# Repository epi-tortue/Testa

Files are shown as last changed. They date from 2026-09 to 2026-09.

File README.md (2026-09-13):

# Testa - conception de coque

Outil de conception et d'optimisation de la coque d'un bateau autonome électrique pour le
[Microtransat](https://www.microtransat.org/) (LOA < 2,4 m), selon la solution
[S1 - coque à ailes inondables](https://epi-tortue.github.io/docs/solutions/s1-coque/) :
coque à déplacement **auto-redressante par la forme**, sans quille lestée, avec deux
**ailes latérales creuses** percées de trous qui portent les panneaux solaires, un
**pont bombé étanche** qui joue le rôle du pont intérieur, et un **lest interne**.

L'objectif est de trouver la géométrie (coque + ailes + lest) qui **maximise l'énergie
solaire produite par rapport à l'énergie de propulsion**, sous contrainte
d'auto-redressement depuis 180° ailes noyées, de franc-bord et de largeur hors-tout.

## Installation

```bash
python3 -m venv .venv && source .venv/bin/activate
pip install -r requirements.txt
```

## Utilisation

```bash
python3 -m coque.params                 # bornes et défauts des 19 variables
python3 -m coque.mesh                   # maillage de la coque de référence + contrôle d'étanchéité
python3 resolve.py --test               # rapport complet de la coque de référence -> outputs/test_*
python3 resolve.py --test --valeurs x.json
python3 resolve.py                      # optimisation CMA-ES multi-départs (reprise automatique)
python3 chercher_coques_redressantes.py --n 256   # balayage Sobol -> CSV + top coques GO
python3 trace_top_go.py                 # courbes GZ réel / A / B des meilleures coques
pytest                                  # validation (formes analytiques, étanchéité, non-régression)
```

## Ce que calcule le score

```
score = production solaire [Wh/j] × cos(gîte moyenne sous 7 m/s)
        / énergie pour 1 km à 1 m/s [Wh/km]  -  pénalités
```

- **Production** : aire projetée du pont de coque + dessus des ailes, × taux de couverture,
  × 615 Wh/m²/j (moyenne route Atlantique N., voir `plt/pont/pont_solaire.py`), × cos de
  la gîte statique sous le vent moyen `VENT_MOYEN` : une coque molle navigue couchée et
  ses panneaux ne voient plus le ciel.
- **Énergie** : frottement ITTC-57 + facteur de forme + vague forfaitaire + fardage
  (vent apparent moyen `VENT_APPARENT`), rendements hélice et chaîne électrique.
- **Tenue au vent** (`vent.py`) : couple de gîte = pression dynamique × Cd × (œuvres
  mortes × cos φ + plateau solaire × sin φ) × bras, comparé à M·g·GZ(φ). La gîte
  d'équilibre sous `VENT_GITE` (10 m/s, ~20 nds) doit rester sous `GITE_VENT_MAX` (12°)
  et sous l'angle d'inondation moins `MARGE_INOND_VENT` (5°). C'est ce critère qui
  dimensionne la raideur initiale, plus que le plancher GM0.
- **Rendement des panneaux** : sous le vent moyen (7 m/s) la gîte doit rester sous
  `GITE_MOYENNE_MAX` (5°) et l'aile sous le vent hors de l'eau avec `MARGE_CONTACT_AILE`
  (2°) : une aile qui traîne n'est pas dans le modèle de traînée, et c'est la coque nue
  qui doit tenir le vent moyen, pas l'appui sur une aile. En dessous de l'angle de
  contact de l'aile, la courbe GZ utilisée pour la gîte sous le vent est GM0·sin φ (coque
  seule) : interpoler le segment 2°–10° de la grille vers un GZ(10°) déjà porté par l'aile
  surestimait la raideur à 4–6° et l'optimiseur s'y était engouffré (écart grille/rapport
  de 49 points sur un run).
- **Robustesse** : tous les critères GZ sont évalués avec KG relevé de `MARGE_KG` (1 cm,
  soit ~300 g oubliés sur le pont) : GZ_rob(φ) = GZ(φ) − 1 cm × sin φ.
- **Pénalités** (continues, 200 points par cm de déficit, 20 points par degré ou par
  mm·rad) : GZ_rob < 3 cm sur [90°, 170°], GZ_rob < 0 quelque part (grille + point juste
  après l'inondation de chaque aile), GM0 < 3 cm (équilibre dédié à 2°, indépendant du pas
  de la grille), aire sous GZ_rob de 0 à 60° < 15 mm·rad (réserve dynamique en vagues),
  gîte sous 10 m/s > 12°, aile basse noyée sous 10 m/s, aile basse inondée avant 25° de
  gîte (angle encadré par bissection, la contrainte porte sur la borne basse de
  l'intervalle), franc-bord < 8 cm, ailes dans l'eau au repos, largeur hors-tout > 0,80 m.
  Géométrie impossible / maillage non étanche / coque qui coule : score −10 000 (toujours
  pire qu'une coque valide).
- **Bornes constructibles** : ailes ≥ 4 cm d'épaisseur, nervure de rive ≥ 1 cm, pont
  bombé ≥ 3 cm. Un optimiseur qui ne paie pas la structure met tout à zéro.
- **Piège ailes sèches** : après un chavirage, les ailes mettent des minutes à se remplir
  (vidange calculée ≈ 150 s pour 12 trous de 8 mm). Tant qu'elles portent, la courbe
  « état A » a en général un équilibre stable vers 150–160° (bateau couché sur une aile).
  À chaque équilibre stable de l'état A sur [90°,180°], les trous d'une aile doivent être
  à ≥ `PROFONDEUR_TROU_MIN` (2 cm) sous l'eau, sinon rien ne remplit l'aile et le bateau
  y reste : 200 points par cm manquant. Le rapport liste ces positions. Corollaire de
  construction : des **évents** sur la face intérieure des ailes, sinon l'air ne sort pas.
- **Assiette** : l'équilibre au repos est toujours à assiette libre ; en « assiette
  bloquée » (grille de l'optimiseur) les autres gîtes sont calculées à l'assiette du
  repos, pas à 0. Tirant d'eau, franc-bord (au livet du maître-bau) et garde des ailes
  (point le plus bas des caissons) sont mesurés sur ce plan de flottaison réel.
- **Coque GO de référence** : `references/go_reference.json` est GO sous tous ces
  critères (GM0 13 cm, gîte 4° sous 7 m/s et 12° sous 10 m/s, inondation à 30°,
  GZ_min[90°,170°] 3,1 cm, score ≈ 305). Point de départ conseillé : `python3 resolve.py --valeurs
  references/go_reference.json`. Sur 192 tirages Sobol aléatoires, aucun n'est GO : la
  région faisable est étroite, partir d'une coque GO économise beaucoup de budget.
- **Anti-artefact de grille** : pendant l'optimisation (pas 10°) les seuils GZ/GM0 sont
  surcotés de `MARGE_GRILLE` (2 mm) et le seuil d'inondation de `MARGE_GRILLE_DEG`
  (0,625°, la résolution de la bissection au pas fin) ; l'optimum de chaque run CMA-ES est ensuite revalidé
  au pas fin (5°, assiette libre) et c'est ce score-là qui classe les runs et qui est
  affiché. Un candidat qui n'est « GO » que sur la grille grossière ne peut plus gagner.
  GZ est aussi évalué juste après l'inondation de chaque aile (là où la courbe chute entre
  deux points de grille) et entre dans le contrôle GZ ≥ 0.
- **Rapport** : chaque rapport (et la fin de chaque run CMA-ES) affiche le bilan des
  marges de toutes les contraintes (valeur, seuil, marge, « au seuil » / « VIOLÉE ») et le
  tableau des 19 variables avec leurs bornes et les butées. Une variable en butée est
  dessinée par la borne, pas par la physique : c'est là qu'il faut regarder en premier.
- **Deux classements** : la pénalité étant continue, un quasi-GO peut avoir un meilleur
  score qu'un vrai GO. `resolve.py` exporte donc en priorité la meilleure coque GO au pas
  fin (préfixe `optim`) et, si le meilleur score fin est une autre coque NO-GO, l'exporte
  aussi (préfixe `optim_nogo`).

## Modèle de stabilité

La courbe GZ 0–180° est calculée par carènes inclinées sur les maillages (coque + deux
ailes). Les ailes portent tant que leurs **trous** (bord supérieur extérieur) sont hors
d'eau ; dès qu'un trou passe sous la flottaison à l'équilibre, l'aile est **noyée
définitivement** et ne porte plus (courbe "réelle", CDC §6). Les courbes pures A (ailes
sèches) et B (ailes noyées) sont disponibles pour les rapports. Un filtre rapide (GZ à
172° coque seule) élimine en 0,4 s les coques stables à l'envers.

## Organisation

```
coque/            package
  params.py       constantes, 19 variables libres (bornes + défauts), validité
  geometrie.py    Bézier rationnelle, loft d'anneaux -> maillage étanche orienté
  mesh.py         CoqueMesh : coque paramétrique
  ailes.py        Ailes : caissons (largeur, épaisseur, bord épaissi, trous)
  masses.py       modèle de masses (structure calculée, charge, lest, panneaux)
  hydro.py        Carene : tirant d'eau, surface mouillée, Cb, Cp
  gz.py           Vessel : équilibre incliné, courbe GZ, métriques
  stabilite.py    verdict d'auto-redressement (inondation séquentielle des ailes)
  propulsion.py   résistance, puissance, énergie
  energie.py      production solaire
  objectif.py     evaluer(valeurs) -> dict complet ; score(curseur) -> float
  optim.py        CMA-ES multi-départs + checkpoints
  export.py       STL, JSON, tracé GZ
resolve.py, chercher_coques_redressantes.py, trace_top_go.py   scripts
tests/            pytest
checkpoints/      état de l'optimisation en cours (reprise automatique)
```

## Variables libres (19)

| Groupe | Variables |
|---|---|
| Coque (15) | `L_COQUE`, `B_MAX`, `CREUX`, `DEADRISE`, `FLARE`, `F_BOUCHAIN`, `W_BOUCHAIN`, `X_MAITRE`, `REMPL_AV`, `REMPL_AR`, `B_ETRAVE`, `B_TABLEAU`, `ROCKER_AV`, `ROCKER_AR`, `HAUTEUR_BOMBE` |
| Ailes (3) | `AILE_LARGEUR`, `AILE_EPAISSEUR`, `AILE_BORD` (épaississement du bord extérieur) |
| Masses (1) | `LEST` (kg, au fond) |

Correspondance avec les 5 paramètres d'optimisation du CDC §7 : volume des ailes
(`AILE_LARGEUR`, `AILE_EPAISSEUR`), forme de section (`DEADRISE`, `FLARE`, bouchain),
pont intérieur (`HAUTEUR_BOMBE`), hauteur de G (`LEST`), bord des ailes (`AILE_BORD`).

## Hypothèses à caler

`M_SURF_AILE`, `M_SURF_SOLAIRE`, `VENT_APPARENT`, `SOLAIRE_WH_M2_JOUR`, le terme de vague
(`c_vague`, `r_hump_max`) et les positions des masses (`masses.py`) sont des estimations :
voir les commentaires de `coque/params.py`.

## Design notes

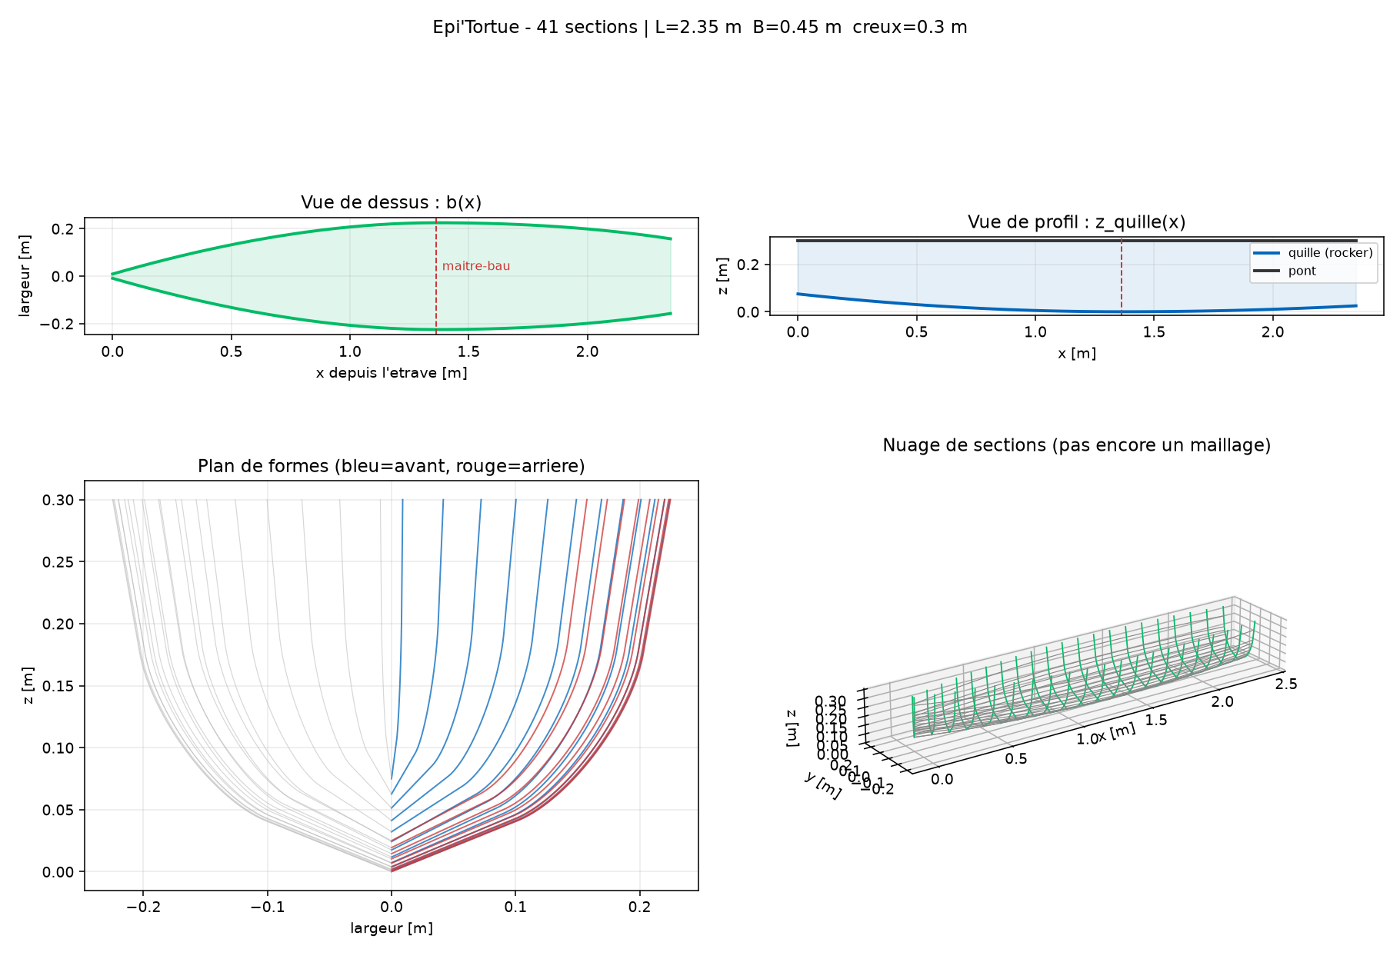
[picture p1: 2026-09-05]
plt/sections_etape2.png

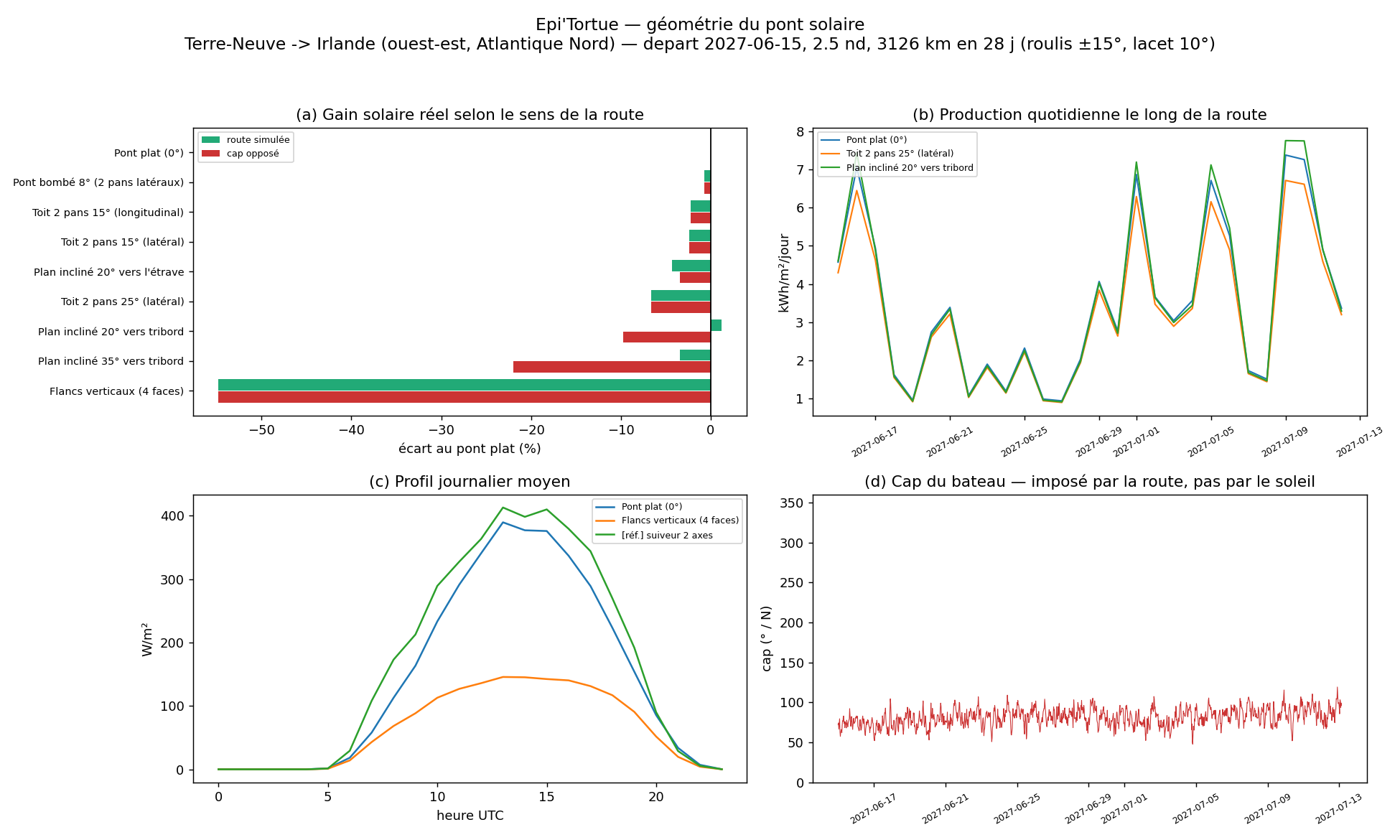
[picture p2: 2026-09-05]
plt/pont/exemple_route_nord.png

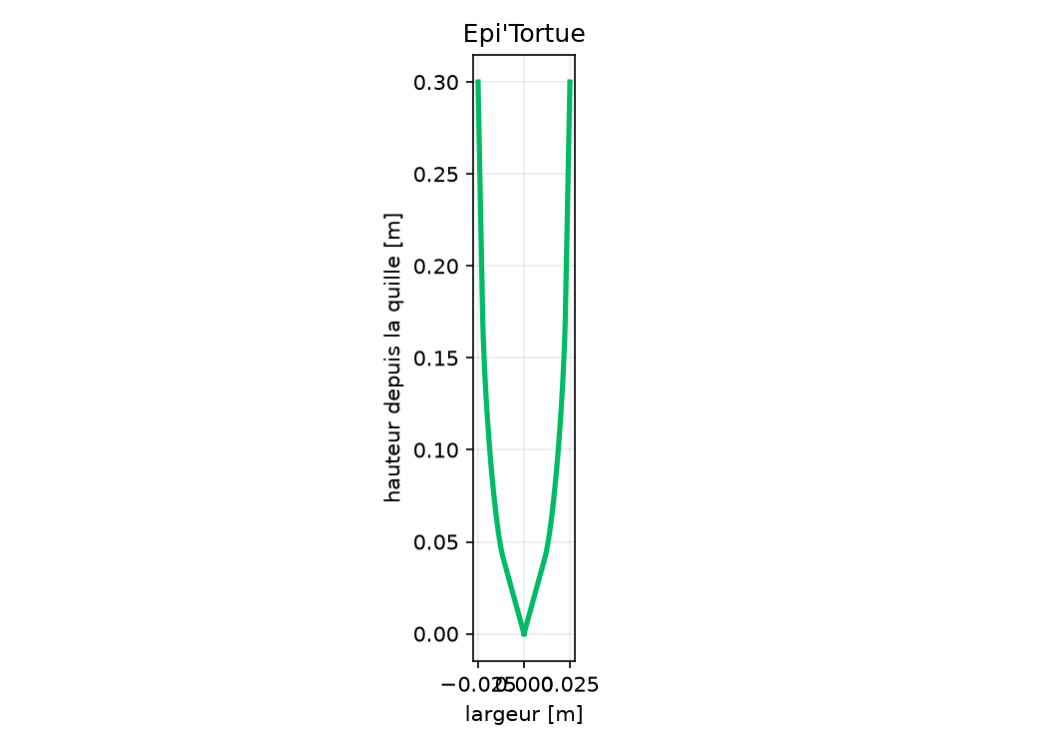
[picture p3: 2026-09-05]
plt/section_etape1.png

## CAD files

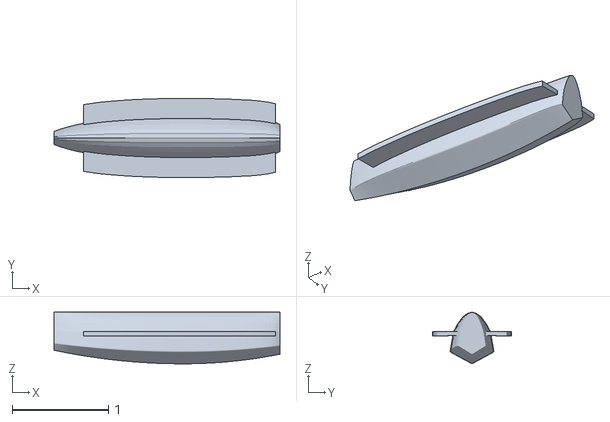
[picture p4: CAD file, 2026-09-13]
outputs/optim_ensemble.stl
2.35 x 0.823 x 0.537

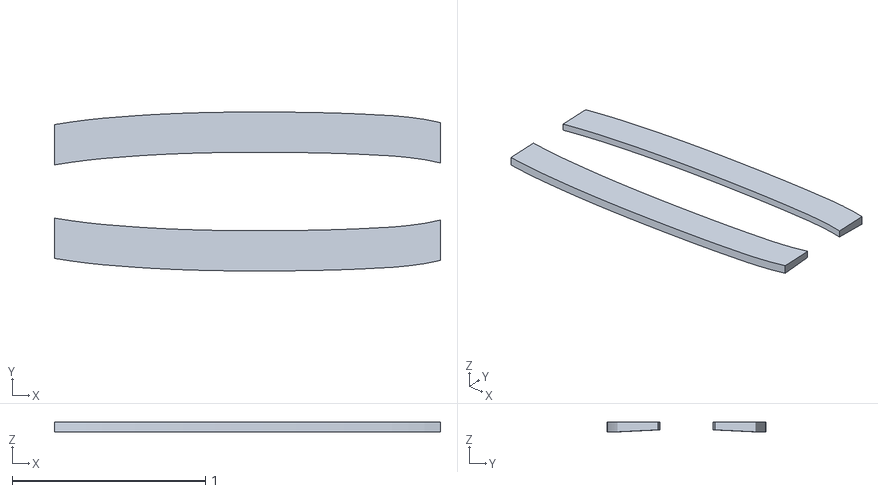
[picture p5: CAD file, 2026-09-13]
outputs/optim_ailes.stl
2.00 x 0.823 x 0.05

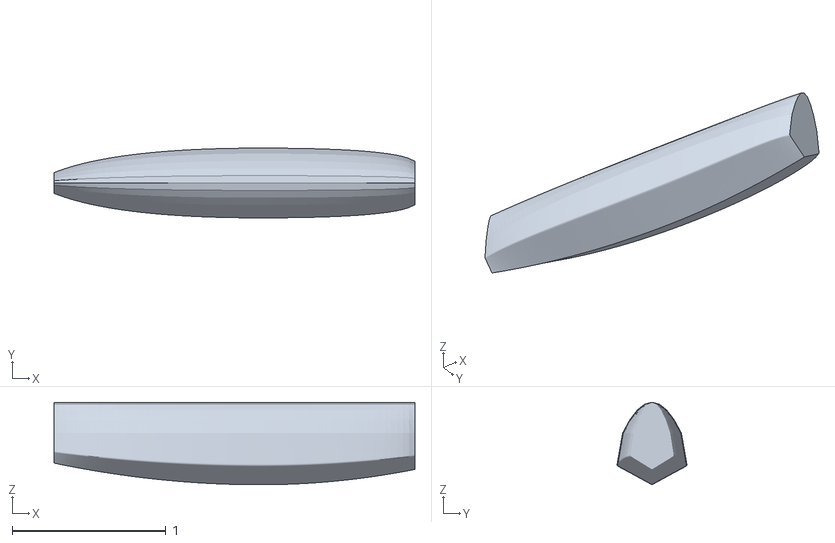
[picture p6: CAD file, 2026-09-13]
outputs/optim.stl
2.35 x 0.454 x 0.537

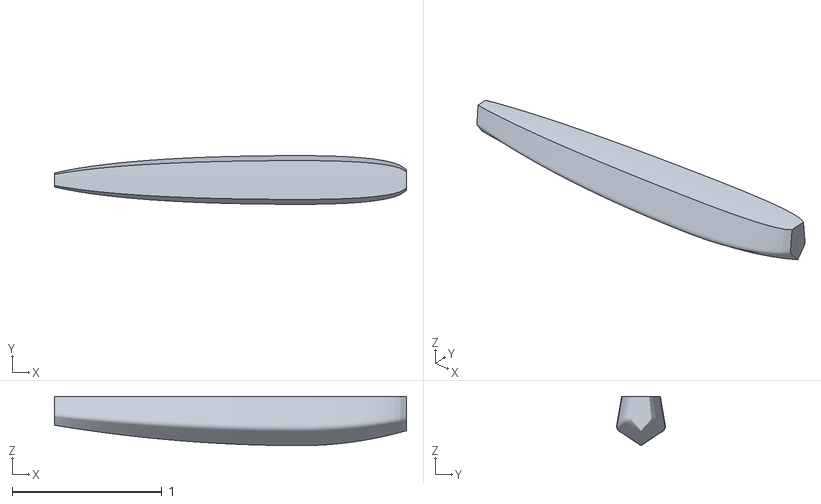
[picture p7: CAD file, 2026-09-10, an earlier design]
outputs copy/optim.stl
2.35 x 0.325 x 0.329

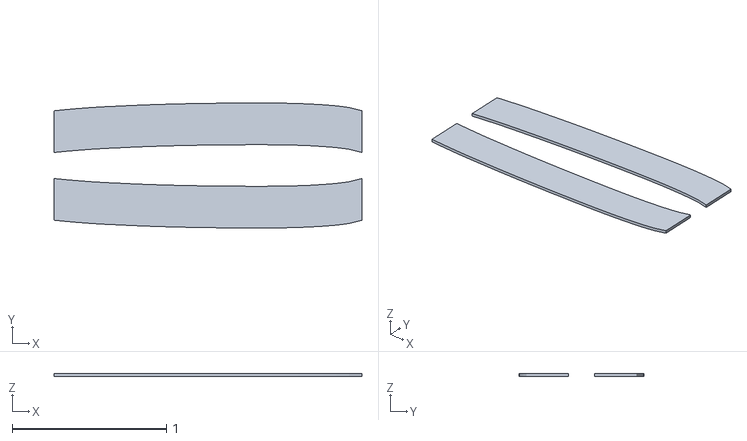
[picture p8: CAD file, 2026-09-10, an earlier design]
outputs copy/optim_ailes.stl
2.00 x 0.811 x 0.02

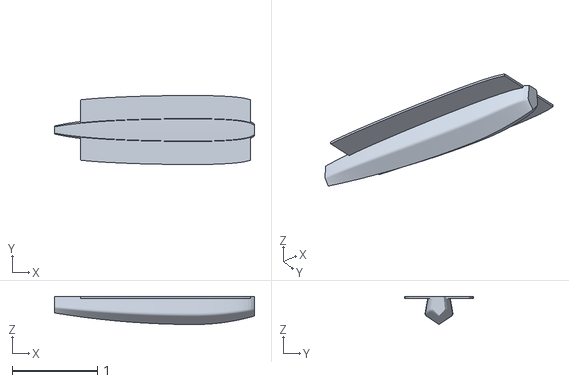
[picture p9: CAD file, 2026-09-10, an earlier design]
outputs copy/optim_ensemble.stl
2.35 x 0.811 x 0.329

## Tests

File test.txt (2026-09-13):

 ── run 11/16 terminé : 6256 évaluations, 391 générations, 206.1 min (0.51 éval/s), sigma final 0.0113, arrêt : maxfevals
       score grille    253.99 | score fin    257.84 = prop 257.84 - pénalité 0.00 | GO=True
       écart grille/fin +3.85 pts  (assiette libre et pas 5° contre 10° bloquée)
       === Candidat ===
       L_COQUE=1.648, B_MAX=0.3892, CREUX=0.3697, DEADRISE=28.86, FLARE=27.66, F_BOUCHAIN=0.776, W_BOUCHAIN=0.2737, X_MAITRE=0.7, REMPL_AV=0.3, REMPL_AR=0.5228, B_ETRAVE=0.1816, B_TABLEAU=0.7715, ROCKER_AV=0.1498, ROCKER_AR=0.09995, HAUTEUR_BOMBE=0.03, AILE_LARGEUR=0.0938, AILE_EPAISSEUR=0.04001, AILE_BORD=0.01013, LEST=9.989
       largeur hors-tout 0.577 m  volume ailes 11.8 L
       === Masses ===
       poste                  kg       x       z
       structure coque     10.26   0.894   0.263
       batteries            8.00   1.154   0.045
       moteur+pod           1.50   1.450   0.040
       electronique         2.00   0.742   0.148
       divers               1.50   1.154   0.129
       panneaux             1.58   0.908   0.405
       lest interne         9.99   1.154   0.015
       aile tribord         1.00   0.915   0.347
       aile bâbord          1.00   0.915   0.347
       TOTAL               36.83   1.048   0.138
       === Hydrostatique au repos ===
       T 24.7 cm  volume 35.9 L  S mouillée 0.764 m²  Lwl 1.65 m  Bwl 0.261 m  Cb 0.338  Cp 0.674
       franc-bord 11.0 cm  garde ailes 3.2 cm
       === Stabilité (courbe réelle, ailes noyées à l'immersion des trous ; critères à KG + 1 cm) ===
       GO=True  
       GZ_max 13.4 cm @ 95°  GZ_min[90,170] +3.1 cm @ 170°  AVS 180°  GM0 7.1 cm (à 2°)  dGZ/dφ(180°) -11.6 cm/rad
       inondation des ailes : tribord 26.25°, bâbord 170.625°  (trous émergés jusqu'à 25.62°, mini 25°)
       GZ juste après inondation tribord +3.4 cm  ->  GZ_min sur ]0,180[ (grille + post-inondation) +0.6 cm
       tenue au vent : gîte 4.6° sous 7 m/s (production × 0.997, aile basse touche l'eau à 7.2°), 11.6° sous 10 m/s (maxi 12°, aile basse inondée à 25.6°)
       réserve dynamique : aire GZ 0-60° 46.0 mm.rad (mini 15)  période de roulis 1.3 s
       ailes sèches après chavirage : équilibre(s) stable(s) à 180° (trous à +3.5 cm sous l'eau), 180° (trous à +3.5 cm sous l'eau)  (mini 2 cm pour que l'aile se remplisse)
       === Énergie ===
       panneaux 0.67 m²  production 413 Wh/j  à 1.0 m/s : 2.45 N (air 0.26 N)  5.8 W  1.60 Wh/km
       SCORE 257.84  (prop 257.84, pénalité 0.00)
       === Marges sur les contraintes ===
       contrainte                            valeur        seuil     marge
       GZ_min [90°,170°]  (KG+1cm)             3.10   >=     3.00     +0.10 cm  <- au seuil
       GZ_min ]0°,180°[   (KG+1cm)             0.62   >=     0.00     +0.62 cm
       GM0 à 2°           (KG+1cm)             7.06   >=     3.00     +4.06 cm
       aire GZ 0-60°                          46.01   >=    15.00    +31.01 mm.rad
       inondation aile basse                  25.62   >=    25.00     +0.62 °  <- au seuil
       gîte sous 10 m/s                       11.62   <=    12.00     +0.38 °  <- au seuil
       inondation - gîte(10 m/s)              14.01   >=     5.00     +9.01 °
       gîte sous 7 m/s (panneaux)              4.57   <=     5.00     +0.43 °  <- au seuil
       contact aile - gîte(7 m/s)              2.63   >=     2.00     +0.63 °
       trous au piège ailes sèches             3.48   >=     2.00     +1.48 cm
       franc-bord                             11.00   >=     8.00     +3.00 cm
       garde des ailes au repos                3.18   >=     0.00     +3.18 cm
       largeur hors-tout                       0.58   <=     0.80     +0.22 m
       === Variables de conception et bornes ===
       variable            valeur      min      max  position
       L_COQUE              1.648        1     2.35       48%
       B_MAX               0.3892     0.25      0.5       56%
       CREUX               0.3697     0.15     0.55       55%
       DEADRISE             28.86        0       45       64%
       FLARE                27.66      -10       30       94%
       F_BOUCHAIN           0.776     0.05     0.95       81%
       W_BOUCHAIN          0.2737      0.2        3        3%
       X_MAITRE               0.7      0.4      0.7      100%  <- butée HAUTE
       REMPL_AV               0.3      0.3      0.8        0%  <- butée basse
       REMPL_AR            0.5228      0.3      0.9       37%
       B_ETRAVE            0.1816     0.02      0.3       58%
       B_TABLEAU           0.7715      0.3        1       67%
       ROCKER_AV           0.1498        0     0.15      100%  <- butée HAUTE
       ROCKER_AR          0.09995        0      0.1      100%  <- butée HAUTE
       HAUTEUR_BOMBE         0.03     0.03      0.2        0%  <- butée basse
       AILE_LARGEUR        0.0938     0.05      0.3       18%
       AILE_EPAISSEUR     0.04001     0.04      0.1        0%  <- butée basse
       AILE_BORD          0.01013     0.01     0.08        0%  <- butée basse
       LEST                 9.989        0       10      100%  <- butée HAUTE
       8 variable(s) en butée sur 19

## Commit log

2026-09-05 Initial commit: parametric hull design and optimization tool
    [coque.stl, test.stl, test_ailes.stl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]
2026-09-06 CI: génération des STL via GitHub Actions
2026-09-06 CI: épingler les dépendances + Python 3.10, pytest avant génération
2026-09-06 CI: conftest.py racine pour l'import de coque + deps epinglees
2026-09-06 CI: trimesh[easy] + shapely (bouchage des carenes dans slice_mesh_plane)
    slice_mesh_plane(cap=True) passe par trimesh.path.polygons, qui exige
    shapely ; sans lui le volume immerge sort faux sans erreur -> "coule".
2026-09-08 Refactor stability evaluation and optimization process
    - Removed the binary file `run_state.pkl` from checkpoints.
    - Enhanced the `evaluer` function in `objectif.py` to include a margin parameter for stability checks.
    - Updated the `score` function to accept additional parameters for fine-tuning evaluations.
    - Introduced a new `validation_fine` function in `optim.py` for re-evaluating optimization results under report conditions.
    - Adjusted the CMA-ES multistart process to reflect the new validation scoring.
    - Added new parameters in `params.py` for improved stability and flooding angle calculations.
    - Implemented a refined flooding angle calculation in `stabilite.py` using bisection.
    - Upda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
    [optim.stl, optim_ailes.stl, optim_ensemble.stl]
2026-09-08 Enhance stability evaluation by adding GZ assessment post-inundation and refining export logic for optimal hulls
2026-09-10 Refactor outputs and tests for stability and geometry
    - Updated binary STL files in outputs directory.
    - Removed obsolete test.json and test STL files.
    - Added new go_reference.json for reference values.
    - Modified test_geometrie_mesh.py to ensure non-regression on fixed geometry.
    - Updated test_stabilite_objectif.py with new reference values and improved assertions for stability tests.
    - Enhanced tests for wind resistance and stability equilibria.
    [coque.stl, optim.stl, optim_ailes.stl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]
2026-09-13 final Hull !!!!
    [optim.stl, optim_ailes.stl, optim_ensemble.stl]
